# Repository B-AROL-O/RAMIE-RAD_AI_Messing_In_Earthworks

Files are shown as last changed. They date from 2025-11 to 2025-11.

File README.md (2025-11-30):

---
title: RAMIE-RAD AI Messing In Earthworks
emoji: 🐨
colorFrom: gray
colorTo: pink
sdk: gradio
sdk_version: 5.49.1
app_file: app.py
pinned: false
license: cc-by-sa-4.0
short_description: A local Gradio MCP server controlling a robot platform
tags:
  - mcp-in-action-track-creative
---

# RAMIE

- **Radical**
- **AI**
- **Messing**
- **In**
- **Earthworks**

A local Gradio MCP AI powered wheeled robot, capable of listening, speaking and executing commands, in the vision of the B-AROL-O team

*TRIVIA: The B-AROL-O team likes to use names of Italian wines as acronyms for robots. [RAMIE](https://nebbiaeluce.com/producer/ramie-perosa-argentina/) is a local red wine from my village*

*TRIVIA: "Vino" is the Italian word for Wine. Intel OpenVINO AI runtime is the perfect runtime to run a robot named after an italian wine by italian developers*

## Scope

The scope of this repository is to document the Hugging Face MCP 1° birthday hackaton

The scope of this repository is to document all instruction to replicate in full the robot project

Work is divided in two parts:

- Work that is qualifying for the hackaton itself, that was started 2025-11-14, this includes learning GRADIO, learning MPC, preparing the MCP tools, interfacing ollama with AI models needed

- Work that is not qualifying for the hackaton and was recycled from previous projects and is in this repository in order to make a complete set of instructions to replicate this project. This include the electronics, the mechanical part of the robot, learning the compute board, and learning that was done for ollama testing of the microphone

This felt like a good chance to gather all the disparate documentation and work done over the years in one tidy set of insttructions that can be followed to make one complete platform end to end with the GRADIO/MCP/OLLAMA software being the keystone that glue it all together.

# Documentation

Designs marked with '*(not qualifying for hackaton)* ' are older recycled design that are here for documentation, instruction and completeness purposes and are not qualifying for the scope of the hackaton.  They are either taken as is, or lightly/heavily adapted to serve for the scope of the Hackaton.

## Mechanical Design

I design in OpenSCAD as I like making geometries as code and I like doing everything parametric.

I decided that the robots should be powered by 18650 batteries. Target configuration is 2S2P. For RAMIE I went with an inverted design that is soldered 4S1P to get 14.8V nominal voltage to be compatible with the input regulator for the Latte Panda Lite Board.

- [MEC: 18650 Battery Holder](/Mechanical/Battery%20Holder%2018650%20OpenSCAD) *(not qualifying for hackaton)*
- [MEC: Wheeled Platform](/Mechanical/Wheeled%20Platform%20OpenSCAD) *(not qualifying for hackaton)*

The robot platform is the one I am designing for Latte Panda Lite Board powered AI robots, it was a good fit for this hackaton

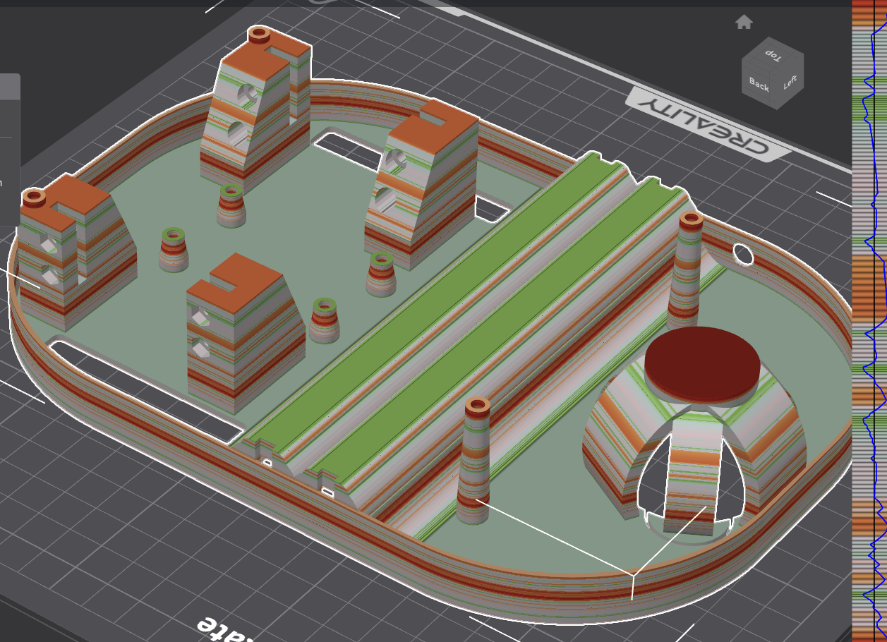
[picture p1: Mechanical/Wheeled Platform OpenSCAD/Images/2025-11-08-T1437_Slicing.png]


## Board Motor Screen

Interfaces with a UART bidirectional link with the SBC, answer to a serial protocol, controls two servos and a LCD screen. Choosen because I had a bounch assembled in a drawer and working firmware to start from.

- [ELN: Board Motor Screen](/Electronics/Board%20motor%20screen) *(not qualifying for hackaton)*
- [FW: Board Motor Screen](/Firmware/Motor%20Board%20Atmel%20AT324PA) *(not qualifying for hackaton)*
- [FW: Test Bench Serial Communication](/Firmware/Test%20Bench%20Parser) *(not qualifying for hackaton)*
- [FW: Test Bench Motion Orchestrator](/Firmware/Test%20bench%20motion%20orchestration)
- [SW: Python demos to test communication between Host computer and board](/Software/Demo_Host_Serial_Communication/)
- [SW: Python demos to test communication between SBC and board](/Software/Demo_SBC_Serial_Communication/)

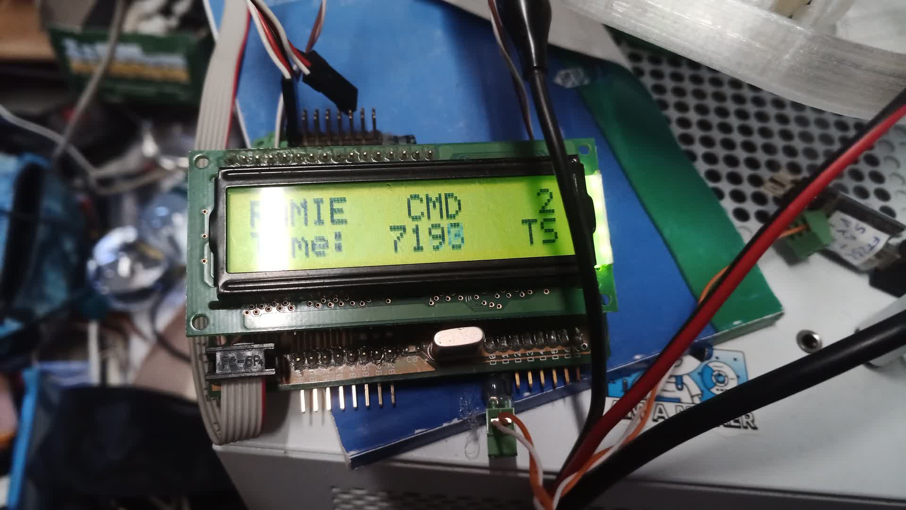
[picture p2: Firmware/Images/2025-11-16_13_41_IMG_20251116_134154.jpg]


# SBC Latte Panda Mu N100 16GB

I lost count of the SBCs I tested for my ultimate goal of making a general robot that expresses a degree of general intelligence with local compute only. The N100 16GB could be it, it has the memory, bandwidth, compute and power envelope to run useful LLMs on the go.

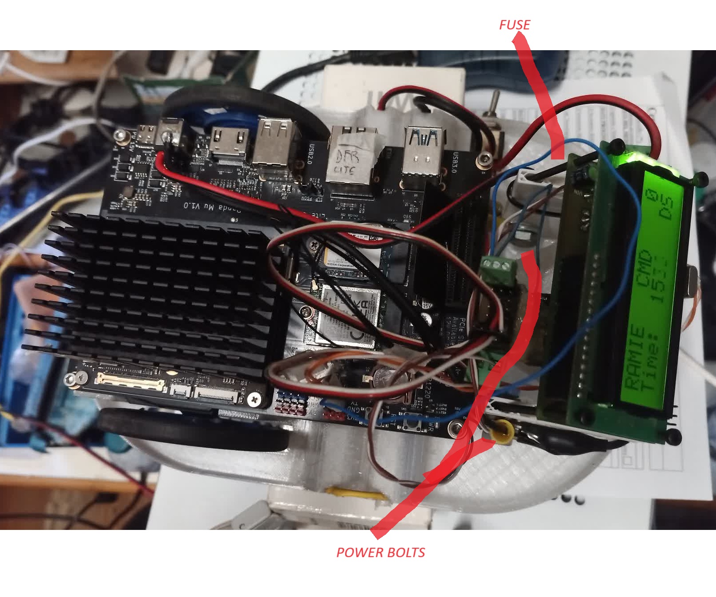
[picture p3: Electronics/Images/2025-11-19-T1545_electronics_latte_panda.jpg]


## Luckfox PicoKVM

I always have trouble accessing SBC headless, I finally got a 49€ KVM to mitigate the issue and free myself from using discrete keyboard and mouse

[Luckfox PicoKVM Instructions](/Software/Luckfox%20PicoKVM)

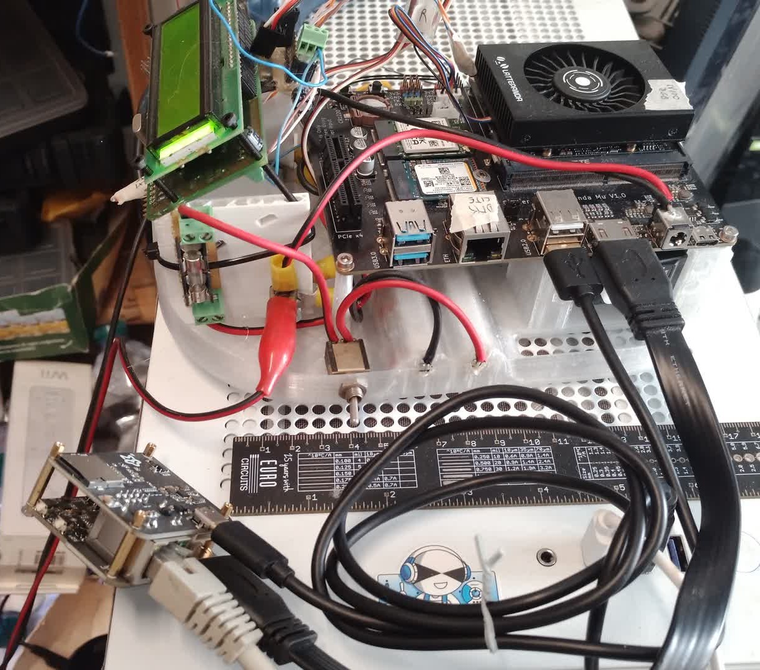
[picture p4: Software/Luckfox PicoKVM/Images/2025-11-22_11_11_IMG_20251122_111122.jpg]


## INSTALL UBUNTU

Install Ubuntu 24.04 Server LTS on the SBC and configure network and storage

[Ubuntu 24.04 Server Install Instructions](/Software/Ubuntu%2024_04%20server%20LTS)

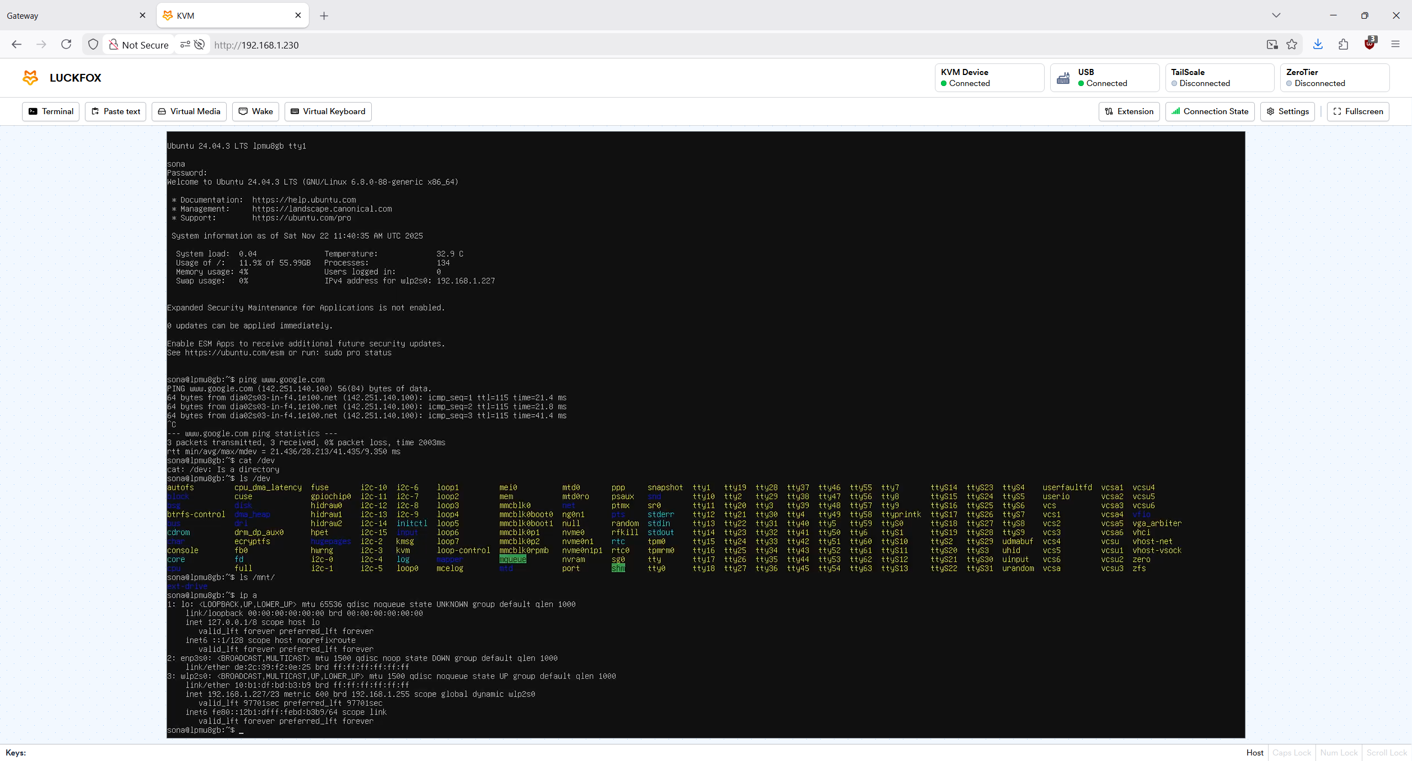
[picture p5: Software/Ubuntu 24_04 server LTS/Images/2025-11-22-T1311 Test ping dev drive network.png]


## Luckfox PicoKVM

I always have trouble accessing SBC headless, I finally got a 49€ KVM to mitigate the issue and free myself from using discrete keyboard and mouse

[Luckfox PicoKVM Instructions](/Software/Luckfox%20PicoKVM)



## TTYS0 SSH PUTTY SERIAL

Configure the GRUB to use ttyS0 as UART serial interface to let the host connect via putty via USB to UART FTDI adapter

[TTYS0 SERIAL GRUB CONFIGURATION](/Software/ttys0%20SSH)

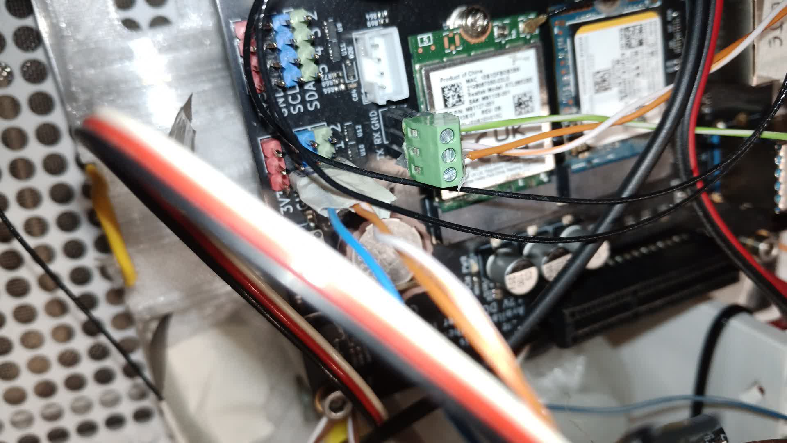
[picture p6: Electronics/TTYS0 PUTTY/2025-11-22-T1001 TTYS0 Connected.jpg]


## VS Code Remote

Use VS code on host machine with remote SSH plugin to evelop and run code directly on the SBC via WiFi radio

[VS Code Remote Instructions](/Software/VS%20Code%20Remote%20Development%20on%20SBC)

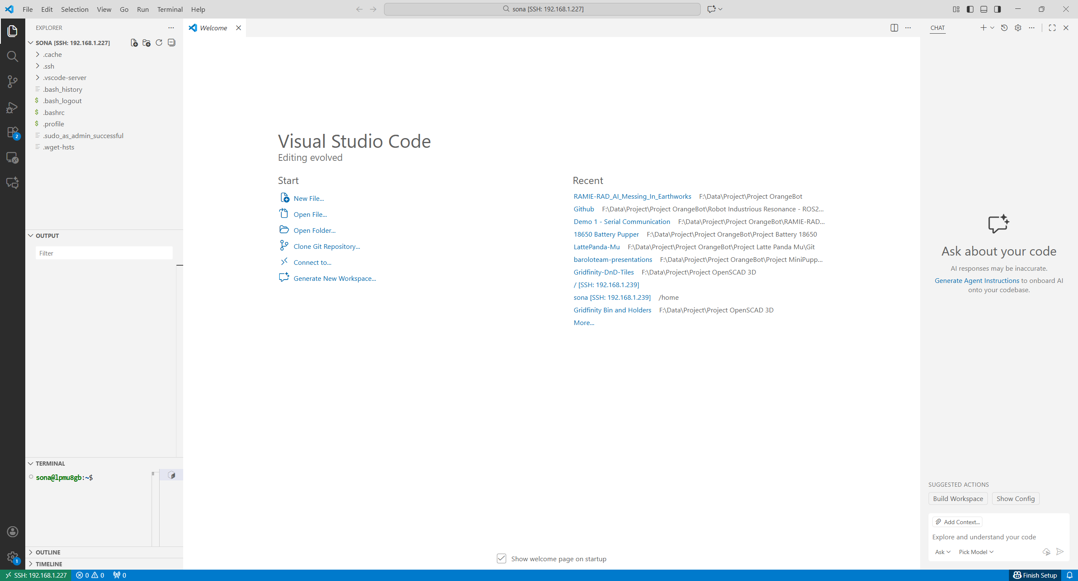
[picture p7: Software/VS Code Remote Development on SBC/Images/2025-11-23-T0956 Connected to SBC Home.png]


# Battery Teleoperation SSH WiFI

Final test with the robot under battery power with SBC, AT324, WiFI and motors running with SSH teleoperation form keyboard

https://github.com/user-attachments/assets/86d634cf-5507-45de-8ebf-013d29c1c32a

# Ollama GRADIO LLamaindex

The robot hosts and run locally GRADIO

There are two chats

One is the chat to ask about RAMIE capability using LLamaindex to rag the specifications

The second has a tool that attaches with a MCP tool to the motors and genereate serial command for the robot to execute

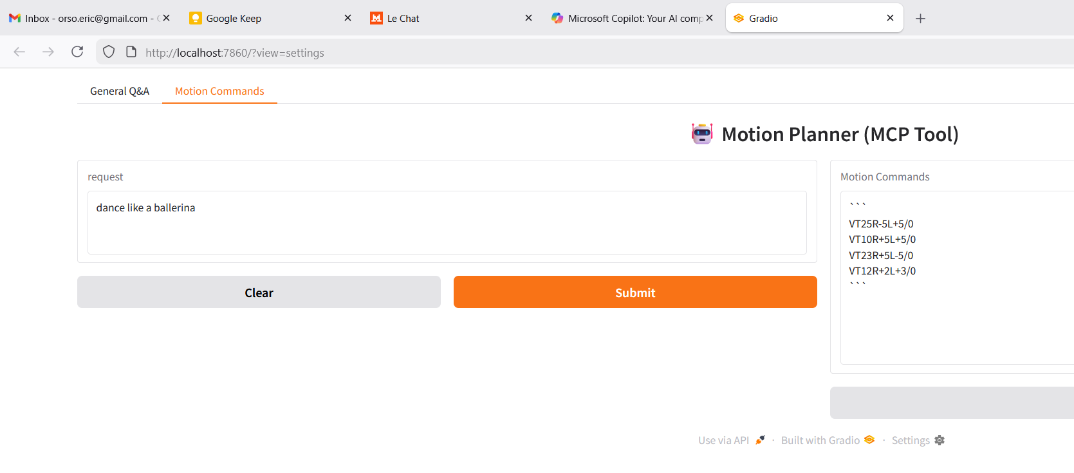
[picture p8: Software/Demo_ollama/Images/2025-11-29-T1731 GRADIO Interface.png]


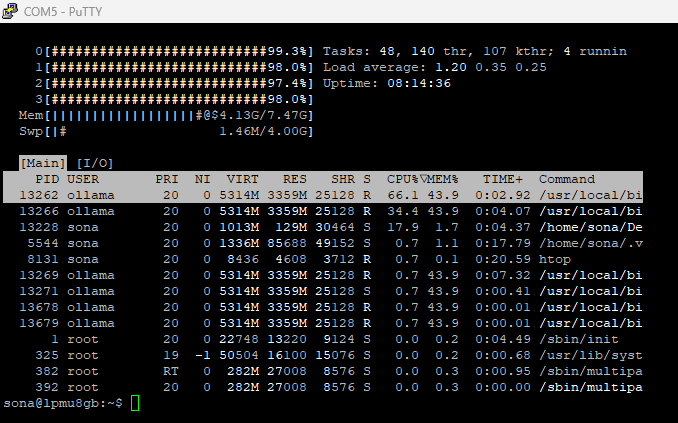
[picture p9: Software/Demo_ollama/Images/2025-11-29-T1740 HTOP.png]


# Contributors

- [Orso Eric](https://github.com/OrsoEric)

## Useful Links

- [Huggingface Hackaton](https://huggingface.co/MCP-1st-Birthday) 
- [Huggingface Example Track 2 Creative](https://huggingface.co/spaces/ysharma/sample5-hackathon-space-submission/blob/main/README.md)
- [Huggingface space](https://huggingface.co/spaces/MCP-1st-Birthday/RAMIE-RAD_AI_Messing_In_Earthworks)
- [Huggingface Organization](https://huggingface.co/RAMIE-RAD-AI-Messing-In-Earthworks)
- [Github repository](https://github.com/B-AROL-O/RAMIE-RAD_AI_Messing_In_Earthworks)
- [Github project board](https://github.com/orgs/B-AROL-O/projects/5)

## TRACK

Track 2: MCP in Action

mcp-in-action-track-creative

# Copyright and License

Copyright (C) 2025, B-AROL-O Team, all rights reserved.

NOTE: This repository is based upon https://github.com/arol-polito/python-project-template.
Source code license

The source code contained in this repository and the executable distributions are licensed under the terms of the MIT license as detailed in the LICENSE file.
Documentation license

CC BY-SA 4.0

Please note that your contribution to the project Documentation is licensed under a Creative Commons Attribution-Share Alike 4.0 License. see https://creativecommons.org/licenses/by-sa/4.0/

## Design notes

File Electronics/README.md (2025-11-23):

# Latte Panda Mu Lite Board

I have three modules

N100 8GB Active Cooling

N100 16GB Passive Cooling

N305 16GB (BRICKED Sent back to DF Robot)

---

# Power

| Voltage  | Current | Power | Note |
|---|---|---|-|
| 18V |  | STOP |
| +10 | +10 | FORWARD 100mm/s |
| -10 | -10 | BACKWARD 100mm/s |
| -10 | +10 | COUNTERCLOCKWISE 180°/s |
| +10 | -10 | CLOCKWISE 180°/s |

# Battery Teleoperation SSH WiFI

Final test with the robot under battery power with SBC, AT324, WiFI and motors running with SSH teleoperation form keyboard

https://github.com/user-attachments/assets/86d634cf-5507-45de-8ebf-013d29c1c32a

## SETUP UART ACCESS TO TTYS0 DEBUG UART

Modify GRUB so that the operating system connects tothe serial port for access

```
cat /etc/default/grub
sudo nano /etc/default/grub
```

Edit the GRUB to make sure the following lines woirk

```
 GNU nano 7.2                                                                                                          
/etc/default/grub *
# If you change this file, run 'update-grub' afterwards to update
# /boot/grub/grub.cfg.
# For full documentation of the options in this file, see:
#   info -f grub -n 'Simple configuration'

GRUB_DEFAULT=0
GRUB_TIMEOUT_STYLE=hidden
GRUB_TIMEOUT=0
GRUB_DISTRIBUTOR=`( . /etc/os-release; echo ${NAME:-Ubuntu} ) 2>/dev/null || echo Ubuntu`

 #2025-11-22 Adding the serial port access via ttyS0 that I ound is the debug consol
GRUB_CMDLINE_LINUX_DEFAULT="console=ttyS0,115200n8"
GRUB_TERMINAL="console serial"
GRUB_SERIAL_COMMAND="serial --speed=115200 --unit=0 --word=8 --parity=no --stop=1"

# If your computer has multiple operating systems installed, then you
# probably want to run os-prober. However, if your computer is a host
# for guest OSes installed via LVM or raw disk devices, running
# os-prober can cause damage to those guest OSes as it mounts
# filesystems to look for things.
#GRUB_DISABLE_OS_PROBER=false

# Uncomment to enable BadRAM filtering, modify to suit your needs
# This works with Linux (no patch required) and with any kernel that obtains
# the memory map information from GRUB (GNU Mach, kernel of FreeBSD ...)
#GRUB_BADRAM="0x01234567,0xfefefefe,0x89abcdef,0xefefefef"

# Uncomment to disable graphical terminal
#GRUB_TERMINAL=console

# The resolution used on graphical terminal
# note that you can use only modes which your graphic card supports via VBE
# you can see them in real GRUB with the command `vbeinfo'
#GRUB_GFXMODE=640x480

# Uncomment if you don't want GRUB to pass "root=UUID=xxx" parameter to Linux
#GRUB_DISABLE_LINUX_UUID=true

# Uncomment to disable generation of recovery mode menu entries
#GRUB_DISABLE_RECOVERY="true"

# Uncomment to get a beep at grub start
#GRUB_INIT_TUNE="480 440 1"
```

Update grub, whatever that means

```
sudo update-grub
```

Log

```
sona@sona-lp-n100-8gb:~$ sudo update-grub
Sourcing file `/etc/default/grub'
Generating grub configuration file ...
Found linux image: /boot/vmlinuz-6.14.0-32-generic
Found initrd image: /boot/initrd.img-6.14.0-32-generic
Found linux image: /boot/vmlinuz-6.14.0-29-generic
Found initrd image: /boot/initrd.img-6.14.0-29-generic
Found memtest86+ 64bit EFI image: /boot/memtest86+x64.efi
Warning: os-prober will not be executed to detect other bootable partitions.
Systems on them will not be added to the GRUB boot configuration.
Check GRUB_DISABLE_OS_PROBER documentation entry.
Adding boot menu entry for UEFI Firmware Settings ...
done
```

Reboot and see if you bricked the OS

```
sudo reboot
```

So, it works and doesn't. On the screen I see ```unsupported port speed``` and on the serial terminal on the host I see that at 9600 I can see the dump

I redid the instruction setting the speed to 115200

---

#### 2025-11-22-T0900 Test Board 2

I powered bypassing the jack and the power button does not work

I connected jack, disconnected uC serial, and it takes a while to power on

I see nothing on the debug uart ttys0

Screen shows no sign of activity

A single click on the power button will shut down the SBC

Shutdown doesn't work

#### 2025-11-22-T1041 Test Board 1

Powered

Checksum error a few reboots

Powered on turn on screen

tested debug uart, see nothing

---

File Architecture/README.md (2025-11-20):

# ARCHITECTURE

## RAMIE

RAMIE is an acronym for:
- RAD Radical
- AI
- Messing
- In
- Earthworks

RAMIE is an MVP AI robot meant to use local 4B LLMs as poor's man AGI and achieve general robotics to an extent.

RAMIE showcasses an end to end STT LLM TTS workflow using MCP tools to sense the robot state and control the robot actions.

RAMIE is menat to run 100% locally without internet connection, all within a small mobile robots, cost, power, memory and compute envelopes.

It has proven most challenging finding an SBC capable of such feats.

## SPECIFICATIONS

- Power: 40 W
- Batttery Duration: ? h
- DoF: 2
- Complexity: MVP

# HARDWARE ARCHITECTURE

## SBC

The single board computer takes care of high level user application and running AI models and required python glue.

RAMIE is powered by the ```Latte Panda Mu N100 16GB``` mounted on a ```Latte Panda Mu Lite Carrier Board```

This board was choosen because of a combination of RAM, RAM bandwidth, compute, power envelope and Intel being one of the two companies in the world that knows how to write drivers and ML frameworks.

## Microcontroller

RAMIE is equipped with a microcontroller board takes care of real time applications, like motor control.

- ```Atmel 324 PA``` 32KB Flash, 4KB SRAM
- ```LCD 2x16``` Display board status
- ```UART 250Kb/s``` Link with the SBC

## Motors

RAMIE moves using two continuous rotation servos using PPM protocol and two wheels with pivot.

Motors are labeled left and right, in this order. The table below will show the robot action when a given speed is sent to the microcontroller board.

| Left Speed  | Right Speed | Robot Motion | 
|---|---|---|
| 0 | 0 | STOP |
| +10 | +10 | FORWARD 100mm/s |
| -10 | -10 | BACKWARD 100mm/s |
| -10 | +10 | COUNTERCLOCKWISE 180°/s |
| +10 | -10 | CLOCKWISE 180°/s |

## Communication Protocol SBC <-> 

Hardware link uses full duplex 250Kb/s link on UART ```ttys4```

The protocol is meant to allow the SBC to read the robot state, and emit robot actions, with the microcontroller firmware taking care of real time operation.

### FEATURE: COMMUNICATION TIMEOUT

The firmware is configured to STOP the motors automatically if no communications is received within a given time limit.

This feature is meant to mitigate the scenario where the SBC application has stalled and the robot will keep executing the last given command, preventing a collision and making it convenient to rearm the robot.

Typical timeout configuration is 1000ms

### FEATURE: DIRECT MODE VS. TIMED MODE

I thought a lot about it, and designed to set of velocity commands to be sent to the SBC.

- Direct Mode: The SBC send a velocity for left and right wheel, and the wheel will move at that speed unless commanded otherwise.
- Timed Mode: The SBC send a timed velocity command that specify a duration in servo step (50Hz). The microcontroller has a queue. This allows the SBC to send a number of motion commands and the microcontroller will execute the commands in sequence for the specified time, then when queue is empty, stop the motors.

Direct Mode is convenient for teleoperation, by binding a velocity to a keystroke down, and velocity zero to keystroke up.

Timed Mode is convenient for LLM orchestration, where the LLM can come up in a single query with a number of motion instructions, and the microcontroller will execute them in sequence. THe SBC isn't going to be convenient for real time anyway, let the microcontroller deal with it.

The microcontroller will seamless switch mode based on last received command, switching will flush the queue of timed commands.

### UART Command Reference (SBC <-> MICROCONTROLLER)

*All messages are ASCII strings terminated by the literal sequence `"/0"` (slash zero). The SBC always sends the terminator; the micro‑controller never sends any data except the replies listed below.*

**RAMIE UART Command Reference (SBC ↔ MC‑U)**  

| Command | Syntax | Arguments | Meaning | Reply (if any) |
|---|---|---|---|---|
| **PING** – refresh communication timeout | `P/0` | – | Resets the internal timeout timer. | None |
| **SIGN** – get robot signature | `SIGN/0` | – | Returns a string identifying the robot. | `RAMIE/0` |
| **REV** – firmware revision | `REV/0` | – | Returns date of current firmware (ISO‑8601). | `2025-11-16/0` |
| **STOP** – emergency stop | `STOP/0` | – | Immediately cuts power to both motors, bypassing acceleration limits and flushes the motion queue. | `STOP/0` |
| **SET VELOCITY** – set constant wheel speed (bypass orchestration) | `VR%sL%s/0` | `R`: right‑wheel speed  (–127 … +127)<br>`L`: left‑wheel speed  (–127 … +127) | Motor controller accepts the two signed bytes and drives each wheel at the requested PWM value. The values are clipped to the legal range. | None |
| **SET TIMED VELOCITY** – enqueue a motion segment | `VT%uR%sL%s/0` | `T`: duration (steps) at 50Hz <br>`R`, `L`: wheel speeds as above | The controller stores the tuple *(right, left, duration)* in its internal queue. When no other command is received, it executes each queued segment sequentially and stops automatically after the last step. Duration is an integer multiple of **1 step = 20 ms** (i.e., one 50Hz cycle). | None |
| **GET BATTERY** – read battery voltage | `GETBAT/0` | – | ? | ? |

### Common Notes

- **Terminators** – Every command string must end with the literal characters `/0`. The micro‑controller responds in exactly the same way (if a reply is defined).  
- **Error Handling** – If an unknown or malformed command arrives, the micro‑controller sends back `ERR/0`. No other action is taken.  
- **Speed Units** – The signed byte values represent PPM 
- **Queue Size** – Timed Mode supports up to 16 motion commands before overflowing. Overflow behaviour is flush.
- **Safety** – The servo driver implements a change in command limit from time step to time step, that is speed for position servos, and acceleration for speed servos.

#### Example Session

```
# Reset timeout
P/0

# Query signature
SIGN/0   → RAMIE/0

# Set constant speeds for 2 seconds
VR10L-10/0
VT20R20L20/0      # queue: forward 3 s (since duration=30 steps)
```

The test bench shows the response to orchestration

```
//MOTIONS QUEUED UP
St_wheel_speed_duration mov1{ 10, -10, 5 };   // spin in place for 5 steps
St_wheel_speed_duration mov2{ 20,  20, 3 };    // forward for 3 steps
St_wheel_speed_duration mov3{-15, 15, 4 };     // spin opposite direction
```

```
//SPEED OF THE MOTORS AT EACH ORCHESTRATION STEP
Step:   1 | R:    10 | L:   -10
Step:   2 | R:    10 | L:   -10
Step:   3 | R:    10 | L:   -10
Step:   4 | R:    10 | L:   -10
Step:   5 | R:    10 | L:   -10
Step:   6 | R:    20 | L:    20
Step:   7 | R:    20 | L:    20
Step:   8 | R:    20 | L:    20
Step:   9 | R:   -15 | L:    15
Step:  10 | R:   -15 | L:    15
Step:  11 | R:   -15 | L:    15
Step:  12 | R:   -15 | L:    15
```

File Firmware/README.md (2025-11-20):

# Firmware

I started from Unit Zero 2019 firmware and the uniparser I built over years. Fixed lots of issues glued together and I have the firmware

I spent many years improving on the uniparser library that allows to register a string and a callback with % argument decoding and it works great! Building custom parsers every time was tedious, and the automatic callback with argument is great at reducing work to do new firmware, it works really well.

TODO

# SBC <-> Board Servomotor LCD Communication

I use a UART 250Kb/s link

The communication is done in clear ASCII characters, easy to do by hand

I use the uniparser library that allows to link commands with % delimiter like a printf to do automatic callback functions with arguments that works really well

Define the callback functions

```cpp
extern void handle_ping(void);

extern void handle_sign(void);

extern void handle_revision(void);

extern void handle_stop(void);

extern void handle_set_velocity(int8_t right_speed, int8_t left_speed);

extern void handle_set_velocity_timed(uint8_t time, int8_t right_speed, int8_t left_speed);
```

Register what command triggers what callback function

```cpp
parser.add_cmd( "P", (void *)&handle_ping );

parser.add_cmd( "F", (void *)&handle_sign );

parser.add_cmd( "REV", (void *)&handle_revision );

parser.add_cmd( "STOP", (void *)&handle_stop );

parser.add_cmd( "VR%sL%s", (void *)&handle_set_velocity );

parser.add_cmd( "T%uVR%sL%s", (void *)&handle_set_velocity_timed );
```

From here the uniparser will take care of everything, and automatically do the function call once the command is received

## TIMEOUT

The firmware is configured to kill the motors if no communications is received, assuming that something went wrong.

TODO: Is it implemented? check.

## PING

This command simply refreshes the communication timeout. 

SBC REQUEST: ```P/0```

BOARD ANSWER: none

## SIGN

This command Ask the board to send the signature, it can be the name of the robot

SBC REQUEST: ```SIGN/0```

BOARD ANSWER: ```RAMIE/0```

## REV

This command ask the board for the firmware revision. It's a date in yyyy-mm-dd ISO format

SBC REQUEST: ```REV/0```

BOARD ANSWER: ```2025-11-16/0```

## STOP

This command is the emergency stop. It stops the motors bypassing the speed and acceleration limits.

SBC REQUEST: ```STOP/0```

BOARD ANSWER: ```STOP/0```

TODO: implements the limit removal

##  SET VELOCITY

Set target velocity of left and right wheels. It is limited by the acceleration of the driver, a safety and continuity measure.

Using this command sets a constant velocity, and bypasses the motion orchestration. Set speed to zero or ask for STOP to stop.

It has S8 arguments, range -127 to +127.

SBC REQUEST: ```VR%sL%s/0```

BOARD ANSWER: none

##  SET TIMED VELOCITY

This specify a time and two velocities. This will engage the motion orchestration, allowing the SBC to queue up motions in a queue, so that when a new speed is sent, it's queued up for execution.

Robot will automatically stop once the last command in the queue is executed.

It's done it this way so that the SBC driver doesn't have to care for the real time orchestration of motion sequences.

SBC REQUEST: ```VT%uR%sL%s```

BOARD ANSWER: none

The test bench shows the response to orchestration

```
//MOTIONS QUEUED UP
St_wheel_speed_duration mov1{ 10, -10, 5 };   // spin in place for 5 steps
St_wheel_speed_duration mov2{ 20,  20, 3 };    // forward for 3 steps
St_wheel_speed_duration mov3{-15, 15, 4 };     // spin opposite direction
```

```
//SPEED OF THE MOTORS AT EACH ORCHESTRATION STEP
Step:   1 | R:    10 | L:   -10
Step:   2 | R:    10 | L:   -10
Step:   3 | R:    10 | L:   -10
Step:   4 | R:    10 | L:   -10
Step:   5 | R:    10 | L:   -10
Step:   6 | R:    20 | L:    20
Step:   7 | R:    20 | L:    20
Step:   8 | R:    20 | L:    20
Step:   9 | R:   -15 | L:    15
Step:  10 | R:   -15 | L:    15
Step:  11 | R:   -15 | L:    15
Step:  12 | R:   -15 | L:    15
```

I need to decide how big is an orchestration step. It should be a finite multiple of 50Hz. I'm thinking 1 mean 100ms. So the maximum 255 means 25.5s

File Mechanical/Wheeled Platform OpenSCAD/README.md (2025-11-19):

# Wheeled Platform

This was lots of work

## SPECIFICATIONS

- Latte Panda Lite Board
- 2S2P battery holder
- Ping Pong pivot ball
- HS422 wheeled servo motors
- AT324 LCD motor controller

## Pivot Ball

I did a fancy geometry to hold a 40mm ping pong ball as pivot. The three petals cut into the base and serve as springs to pull out the ball and hold it gently letting it rotate. All with the heights nailed down to get it leveled.

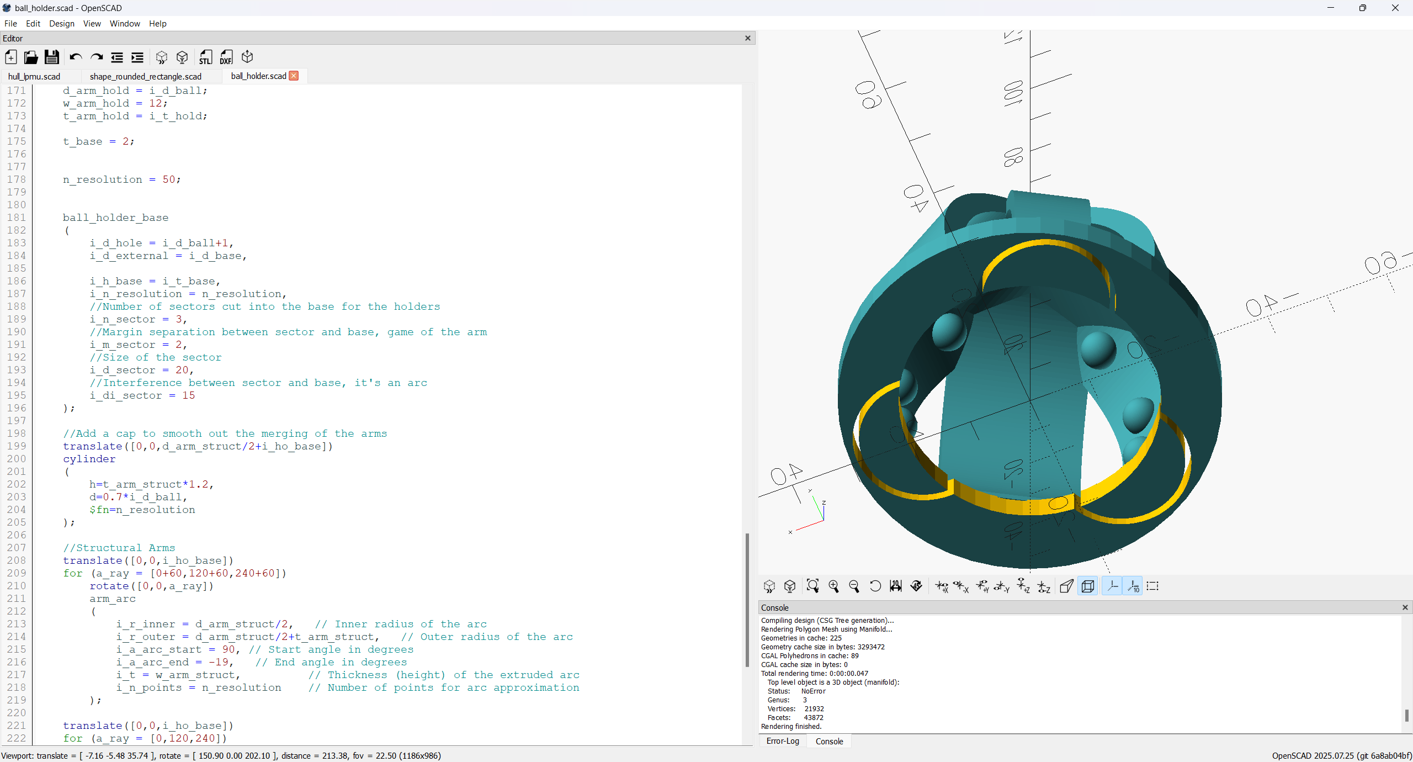
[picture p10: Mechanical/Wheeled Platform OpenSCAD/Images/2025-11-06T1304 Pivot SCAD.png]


## 2S2P Inverted Quad 18650 Holder

Another fancy geometry to hold four batteries with parametric size inverted with the tollerances nailed down so it stays when inverted but can be pulled out. Needs support to print inverted.

I considered various layouts

For a Raspberry Pi dual battery design I can shrink it enormously, that's what I started with, but then pivoted to Latte Panda Mu Board

This version has two banks of two batteries, but ultimately is a lot wider.

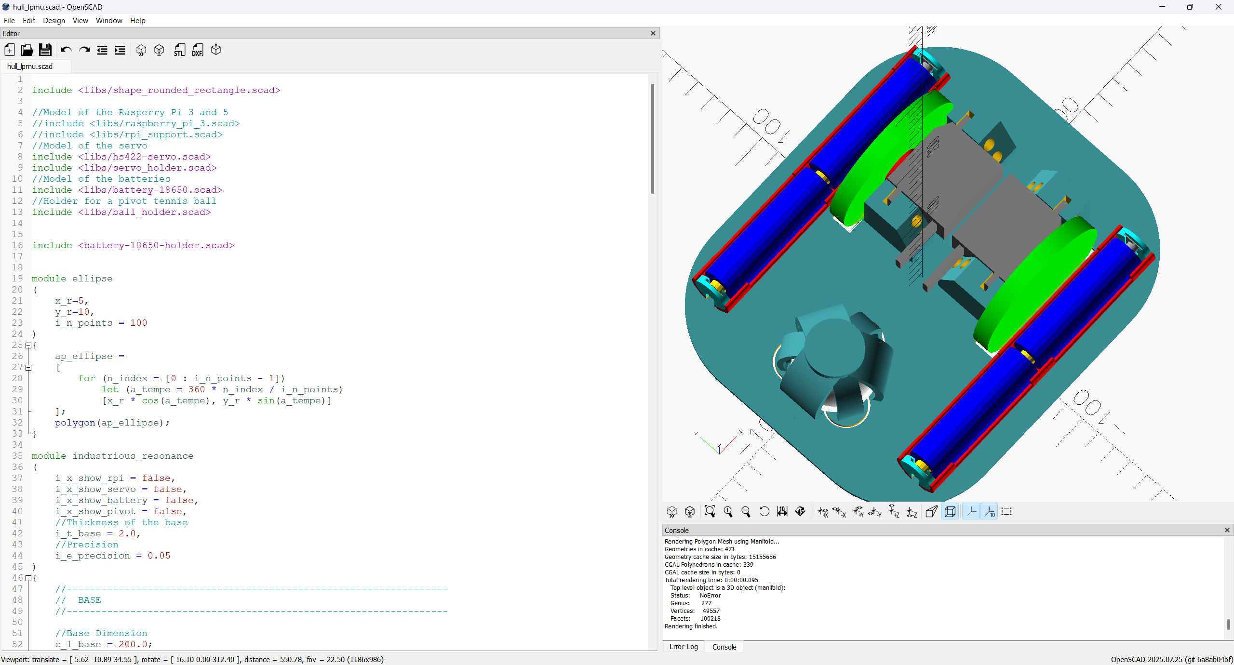
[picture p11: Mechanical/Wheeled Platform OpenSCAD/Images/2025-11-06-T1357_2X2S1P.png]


Ultimately I decided to do it along the width in between wheels and pivot. There is a variation where the batteries stays lengthwise but it makes it much bigger

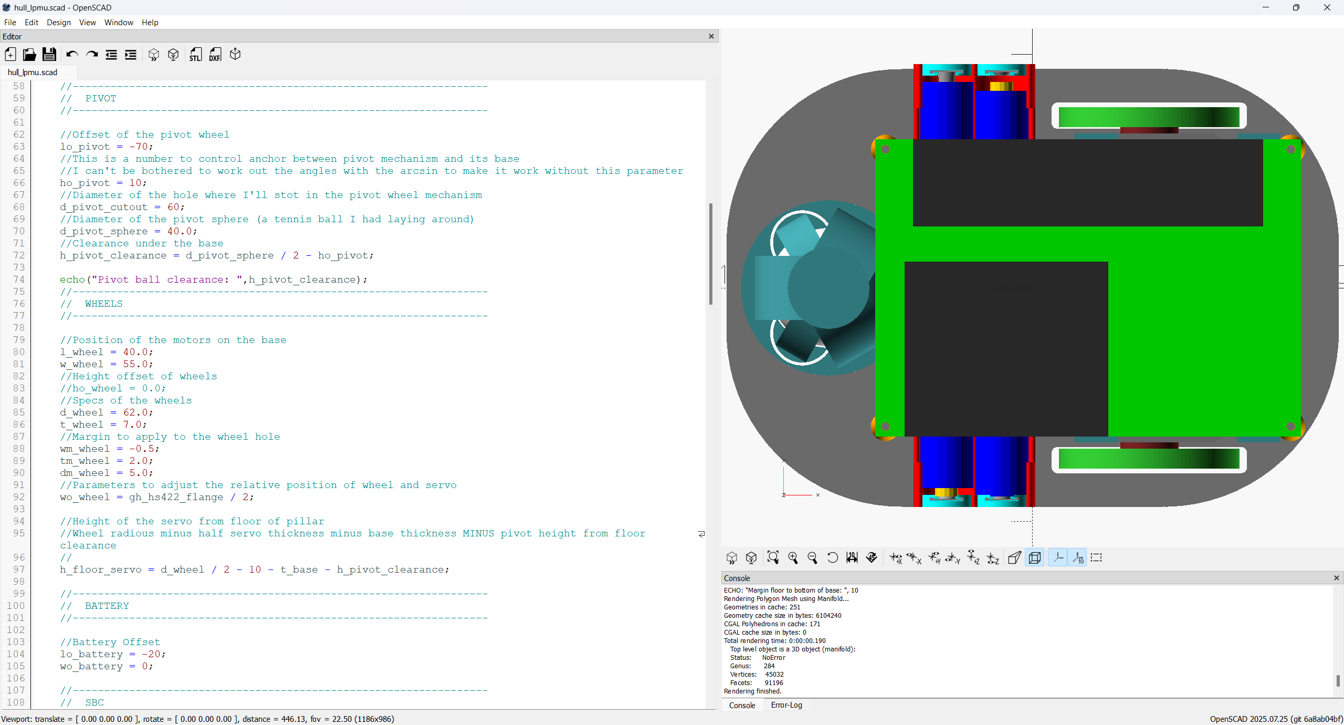
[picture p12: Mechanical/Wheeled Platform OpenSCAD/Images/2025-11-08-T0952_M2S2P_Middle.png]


Then I designed an inverted battery pack to load from below. Much harder to design but worth it.

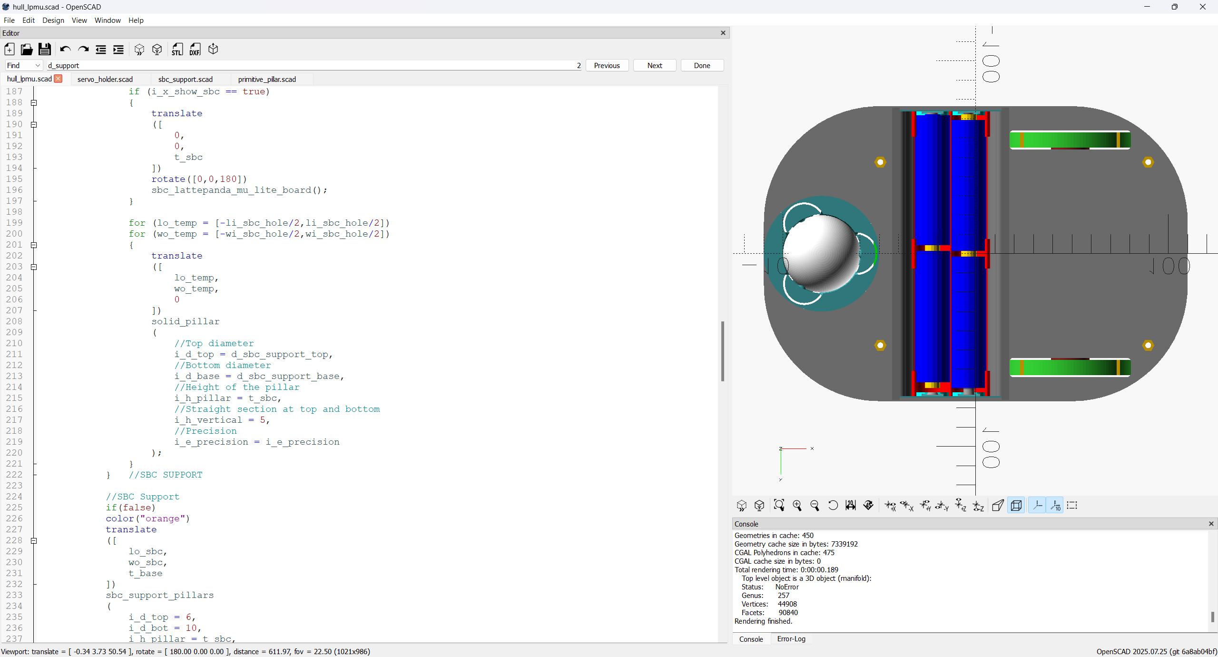
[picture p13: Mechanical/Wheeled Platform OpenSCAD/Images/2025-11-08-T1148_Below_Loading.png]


## HS422 Servo Holder

I have pillars serving as servo holders, I did all the parameters to nail down tollerances and height to keep level, and merged with the SBC pillars.

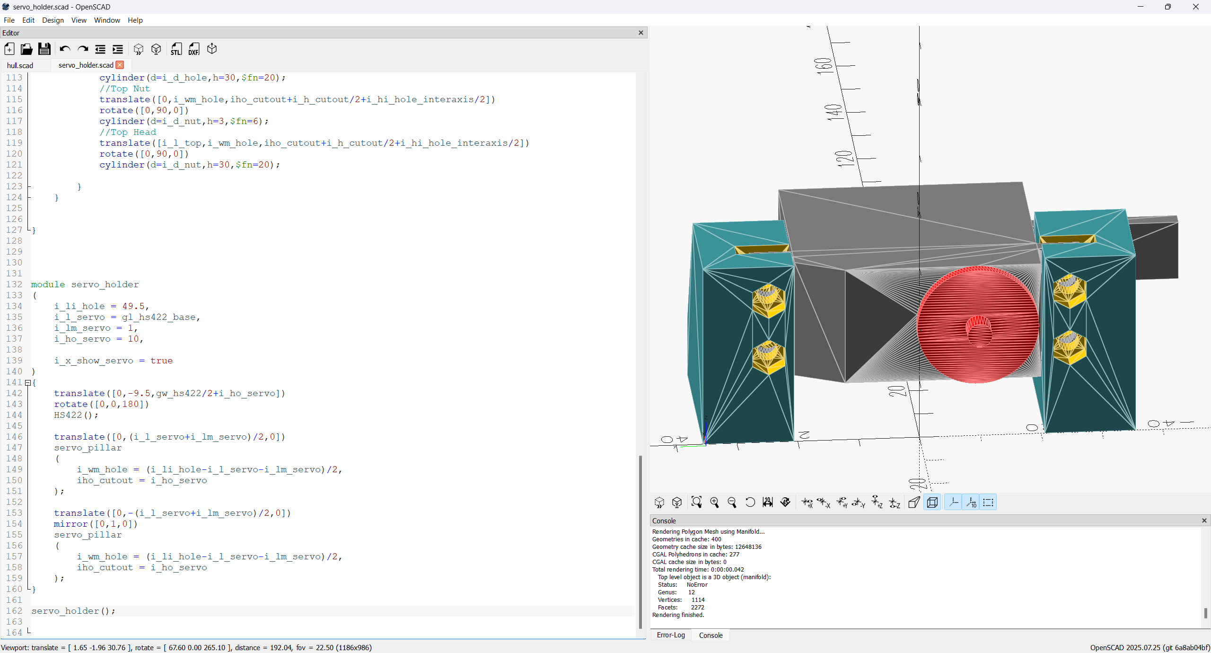
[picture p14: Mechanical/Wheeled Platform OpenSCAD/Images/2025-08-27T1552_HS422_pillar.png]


## AT324 Board

Constructing a sloped wall to support the microcontroller board with LCD

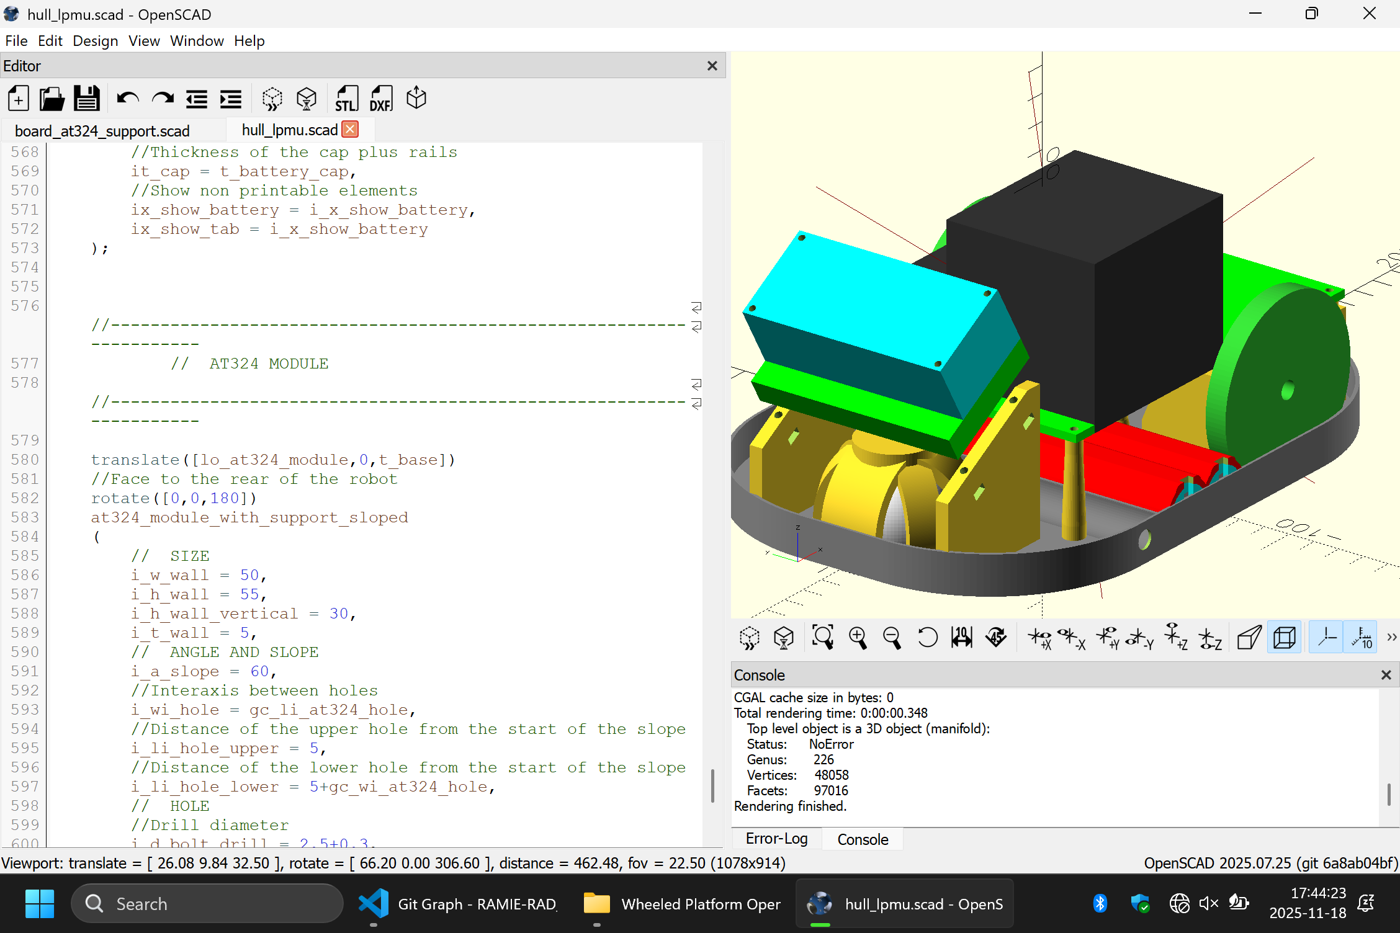
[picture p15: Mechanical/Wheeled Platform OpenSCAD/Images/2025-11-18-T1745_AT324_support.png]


As additional consideration, I can use the support to bolt the power connectors so I have positive and negative side

I whould think of additional structural supports

The rear looks ripe for a camera attachment

Print failed, I did it quick in the evening and failed to use right size and do proper support, it's still useable for the prototype, and I got the bolts right

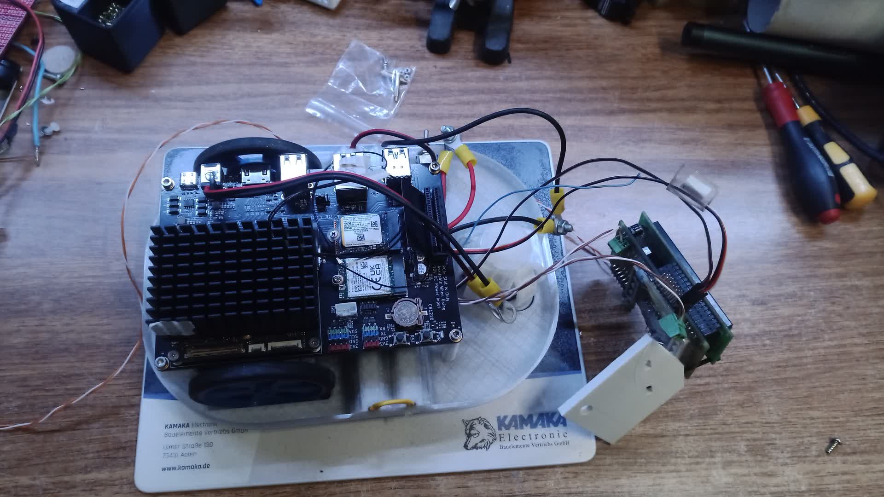
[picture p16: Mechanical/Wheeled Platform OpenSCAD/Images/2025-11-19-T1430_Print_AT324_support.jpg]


Used hotglue to install the support, and it all works well enough.

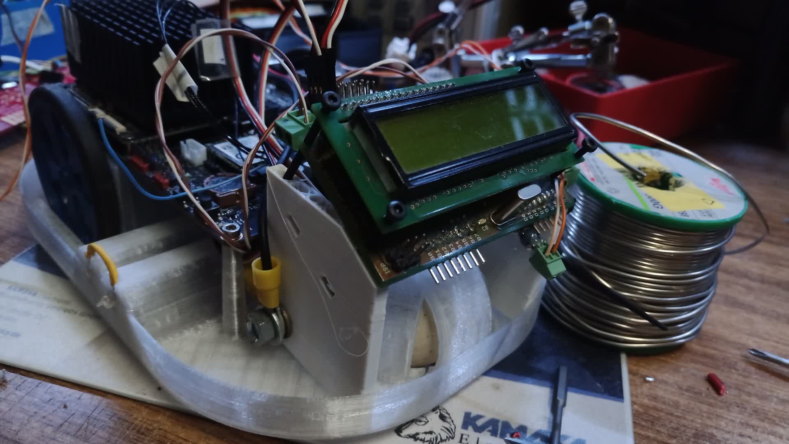
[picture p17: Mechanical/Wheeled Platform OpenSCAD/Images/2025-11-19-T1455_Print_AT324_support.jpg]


## Final Assembly

I did a bath tub style holder with all the components and it turned out okay

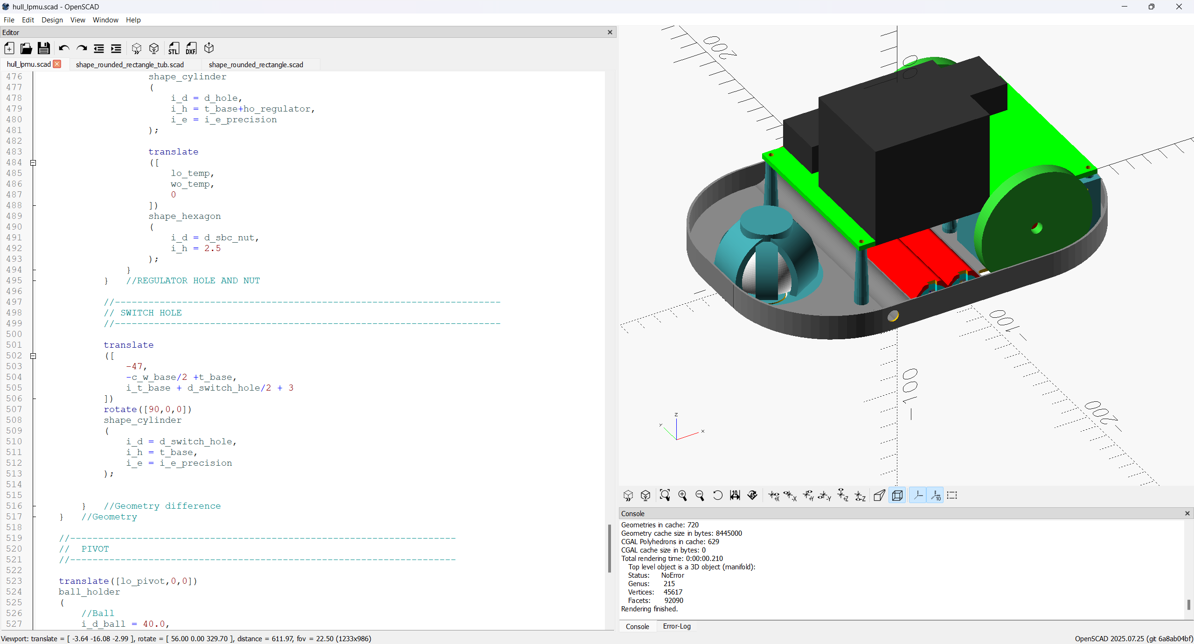
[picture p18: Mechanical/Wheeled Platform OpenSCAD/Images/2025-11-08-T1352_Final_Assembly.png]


Generated the STL and Printed with my Creality K2 with auto loader. I decided to use PETG transparent filament and it came out great! The tollerances are PERFECT.



### TOP VIEW

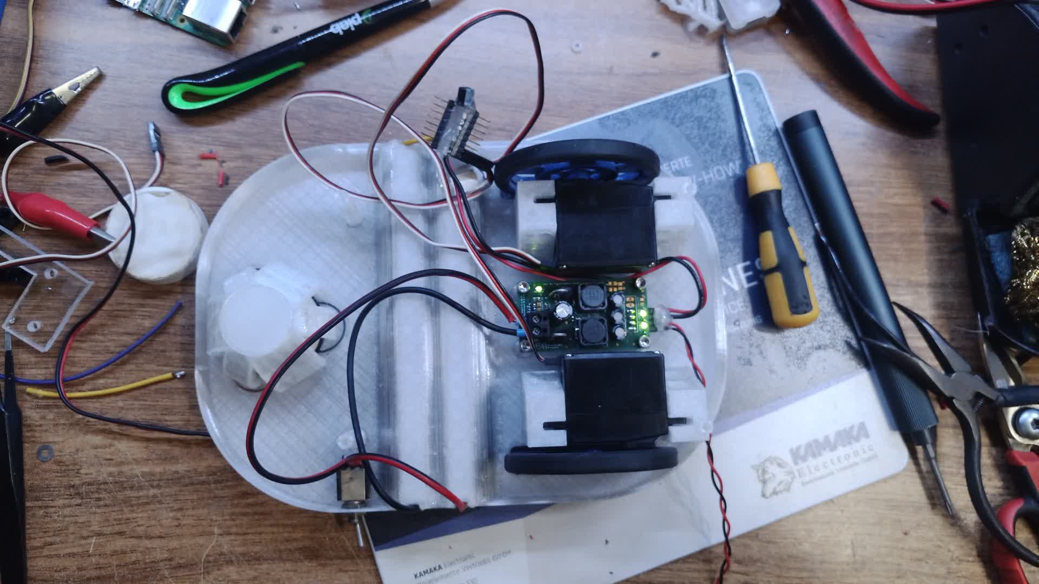
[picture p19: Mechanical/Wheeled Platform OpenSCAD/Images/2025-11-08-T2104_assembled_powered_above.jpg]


### BOTTOM VIEW

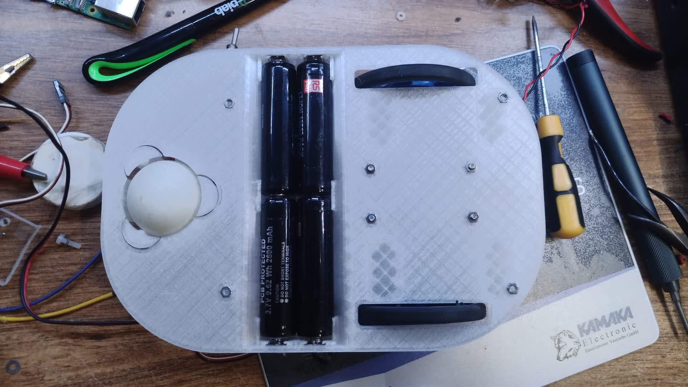
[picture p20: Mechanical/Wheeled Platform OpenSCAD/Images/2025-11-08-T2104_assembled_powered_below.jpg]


### WITH LATTE PANDA

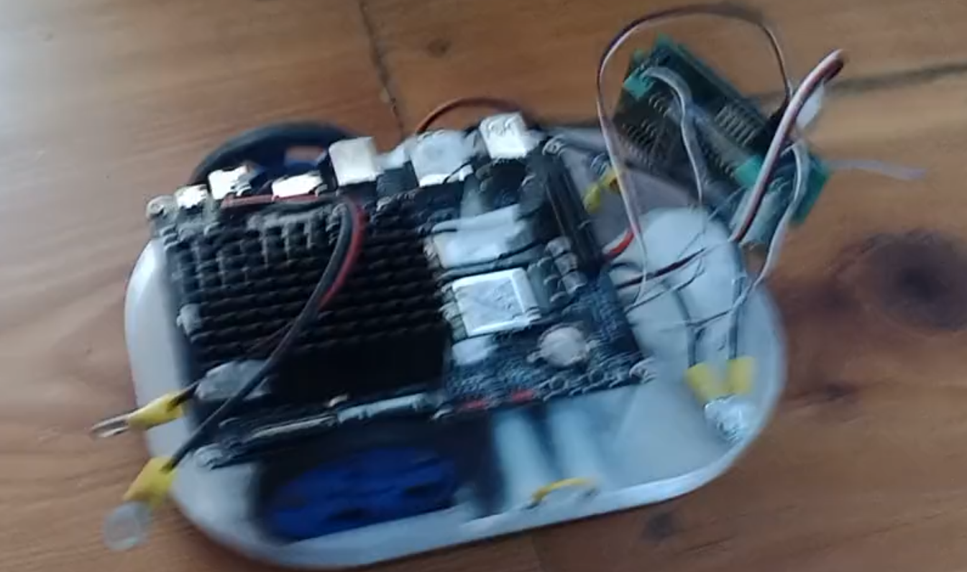
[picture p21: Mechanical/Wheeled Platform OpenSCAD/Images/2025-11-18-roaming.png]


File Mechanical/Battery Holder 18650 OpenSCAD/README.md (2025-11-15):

# 18650 Battery Holder

This is a design for a robot battery holder

# Battery with PCB protection

Length measured to the tip of the button

| Battery | Diameter [mm] | Length [mm] | Capacity [mAh] | Note |
|---|---|---|---|---|
| UltraFlre LI IONBRC  |  18 | 680 | 4800 | I think the capacity is a scam|
| RSPRO LI ION PCB |  18 | 710 | 2600 | |

# Battery Tab 

[RS Component Buy](https://it.rs-online.com/web/p/contatti-per-batterie/3247303)

Size 11x11mm slightly bigger

| Loading | Length [mm] |
|---|---|
| Unloaded | 8 mm |
| Loaded | 3 mm |

# OpenSCAD

Modeling of the parts

## Tab with Spring

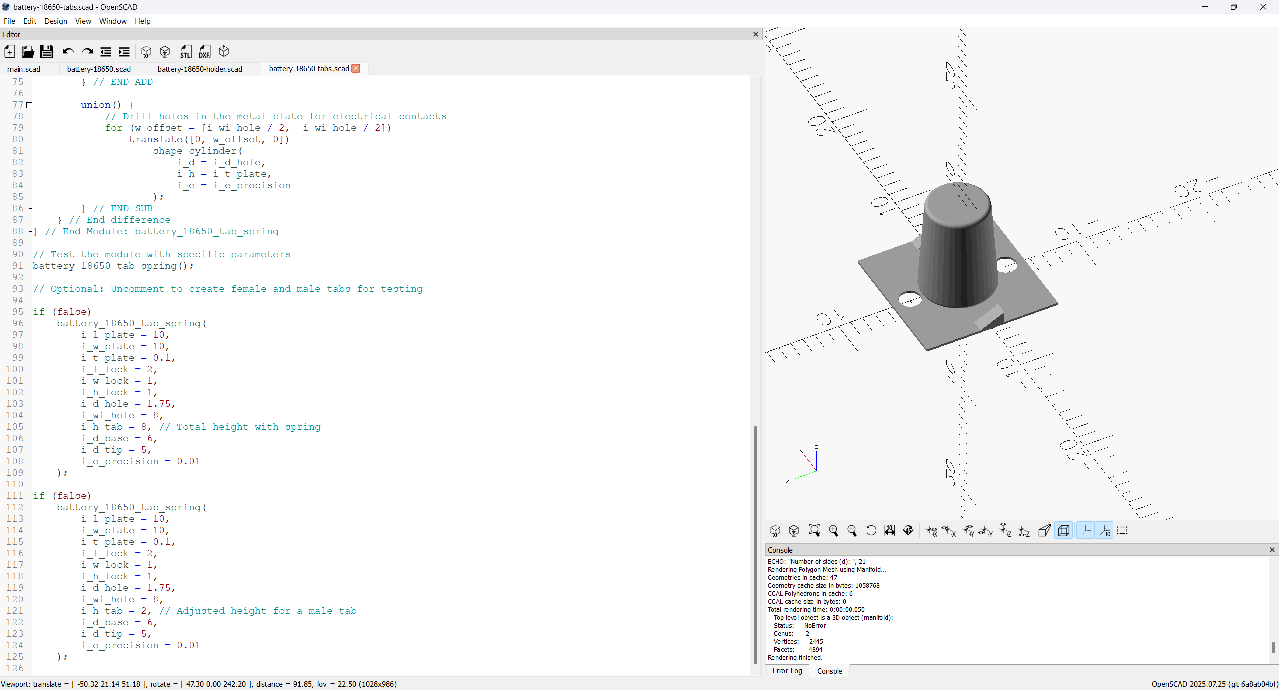
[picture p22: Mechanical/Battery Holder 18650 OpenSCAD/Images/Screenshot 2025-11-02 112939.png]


## Endcap for the battery holder

OpenSCAD

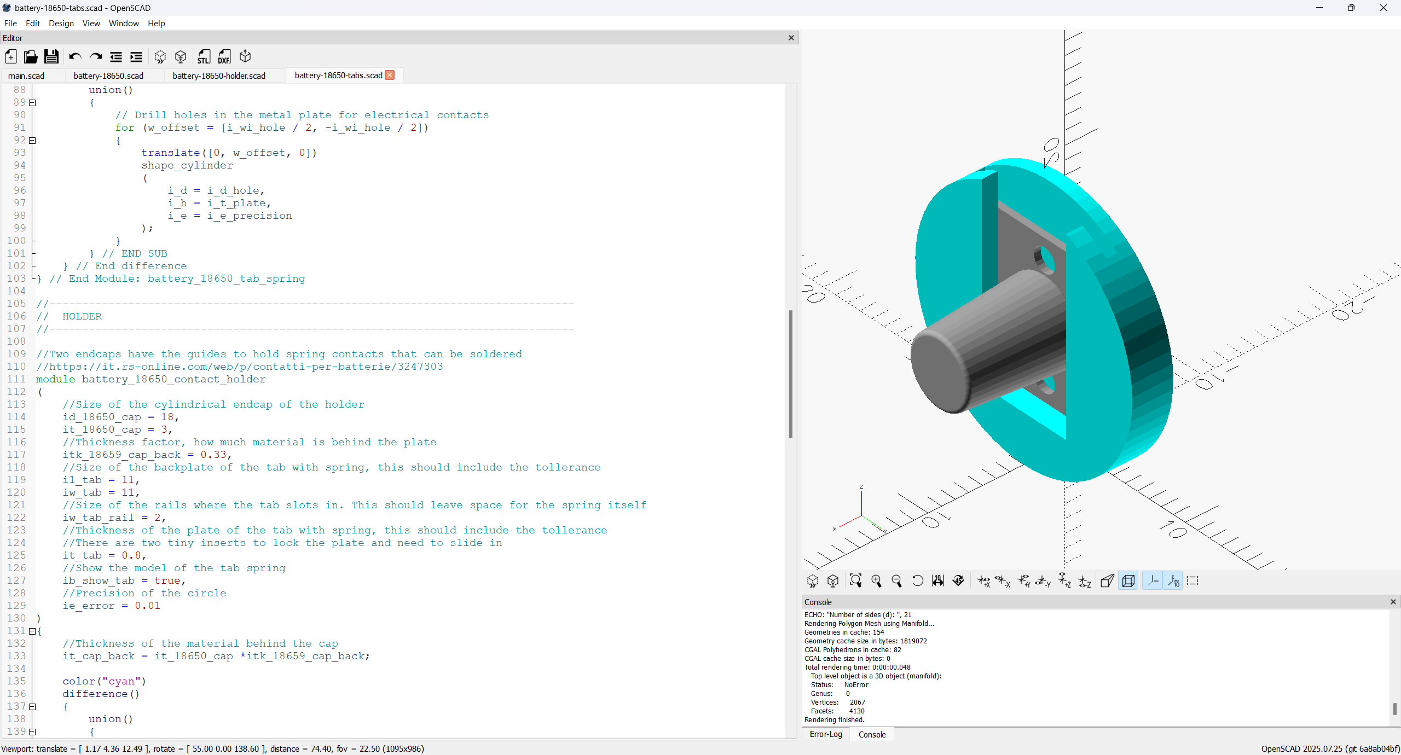
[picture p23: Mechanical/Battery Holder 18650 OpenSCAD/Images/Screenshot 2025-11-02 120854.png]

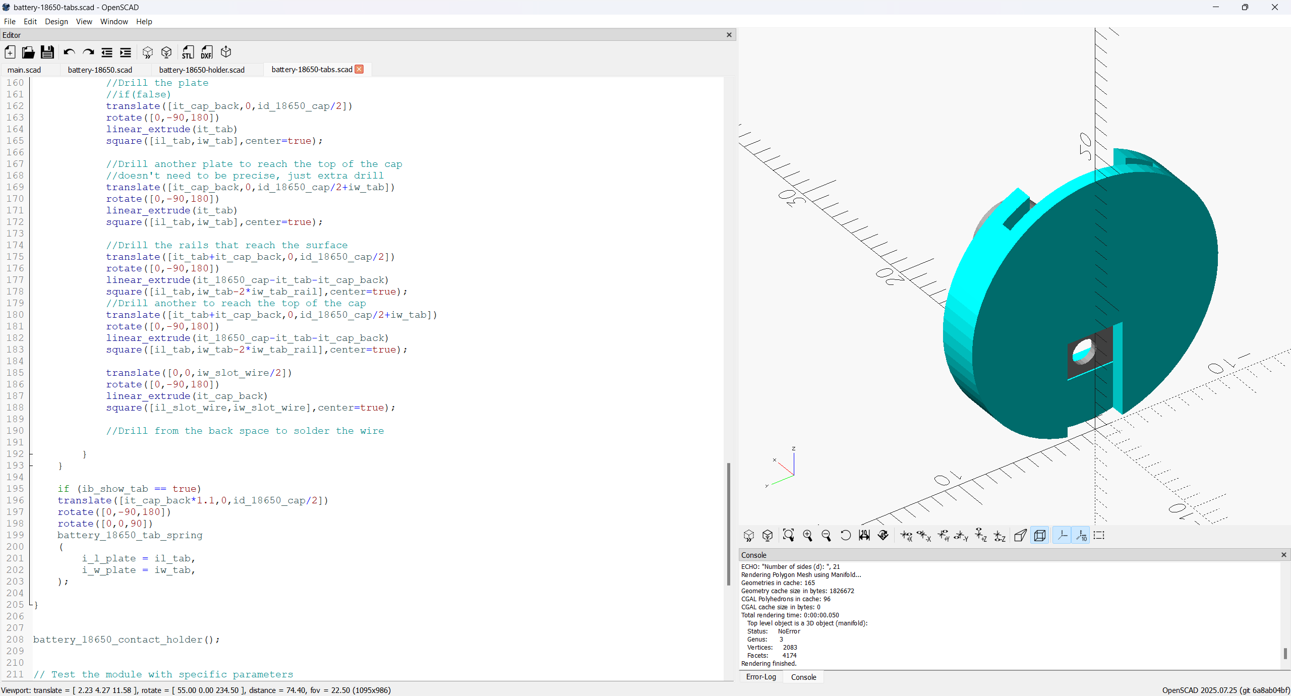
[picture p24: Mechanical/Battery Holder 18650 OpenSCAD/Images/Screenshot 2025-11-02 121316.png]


Printed to test tollerances

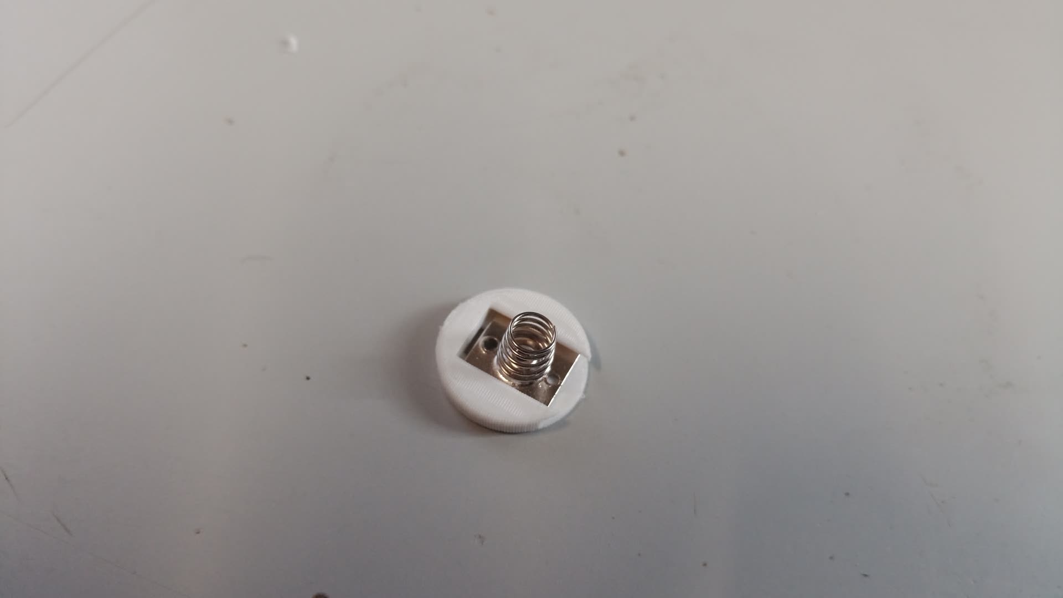
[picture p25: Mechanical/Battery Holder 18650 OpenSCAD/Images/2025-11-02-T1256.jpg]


## Holder 1S1P Single Battery

S mean series, P means parallel

3.7V nominal
4.2V max

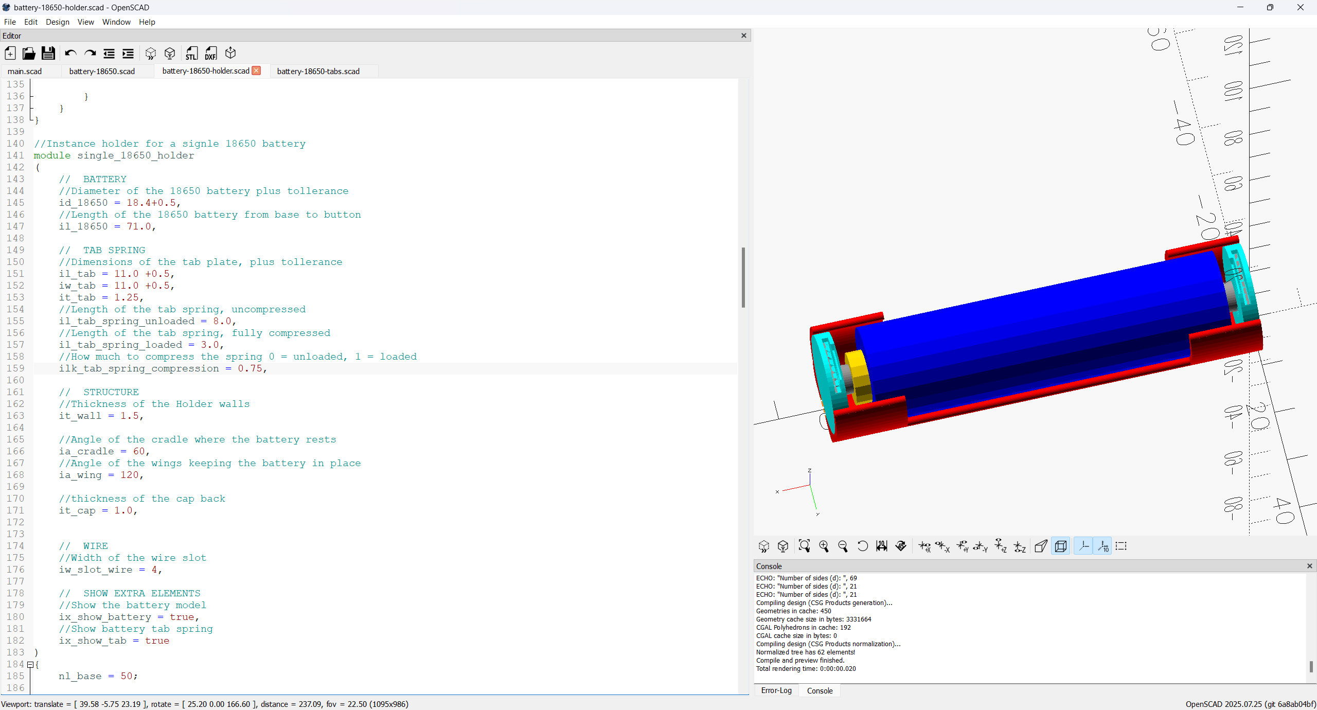
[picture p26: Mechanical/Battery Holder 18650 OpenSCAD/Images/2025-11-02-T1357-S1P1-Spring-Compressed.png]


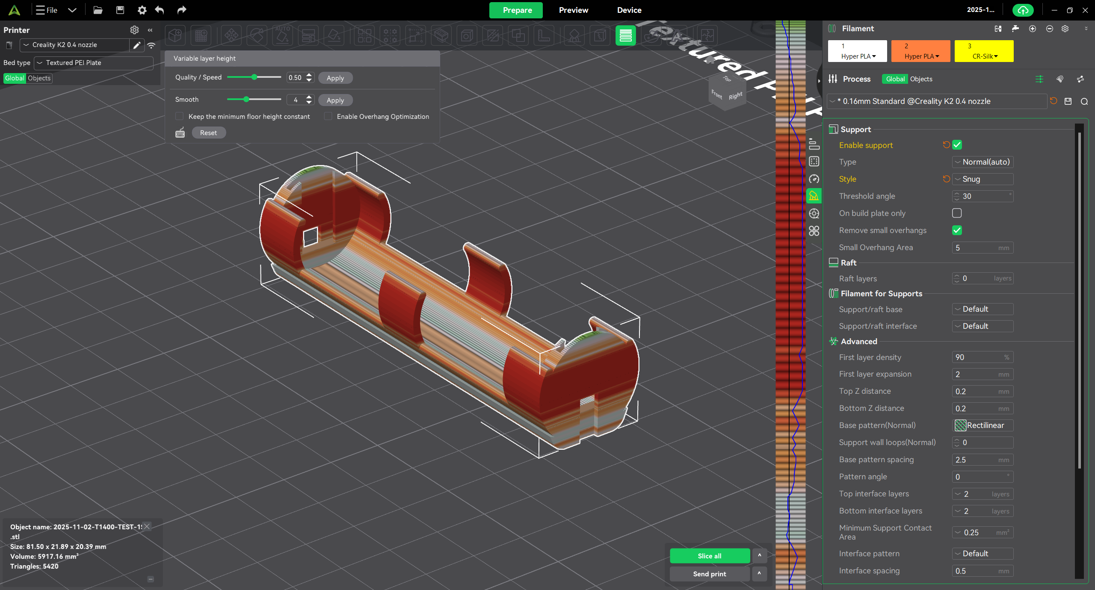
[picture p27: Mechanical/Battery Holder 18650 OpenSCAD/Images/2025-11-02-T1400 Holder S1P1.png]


First test, it's close. Fix:
- I did double spring that's not smart, I do have a button contact for the positive tab
- The center wing is too weak, I need to make it longer
- Ticker construction?

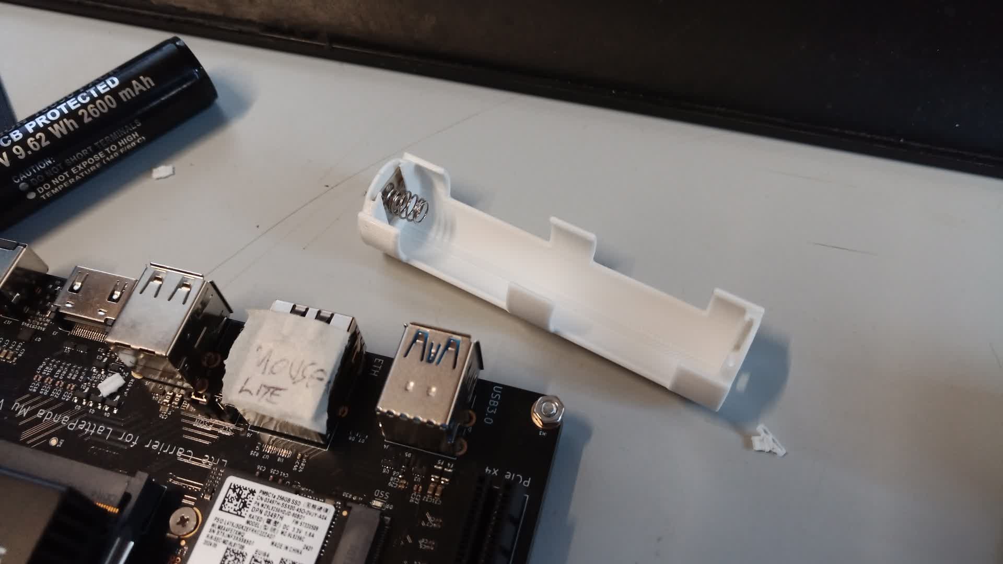
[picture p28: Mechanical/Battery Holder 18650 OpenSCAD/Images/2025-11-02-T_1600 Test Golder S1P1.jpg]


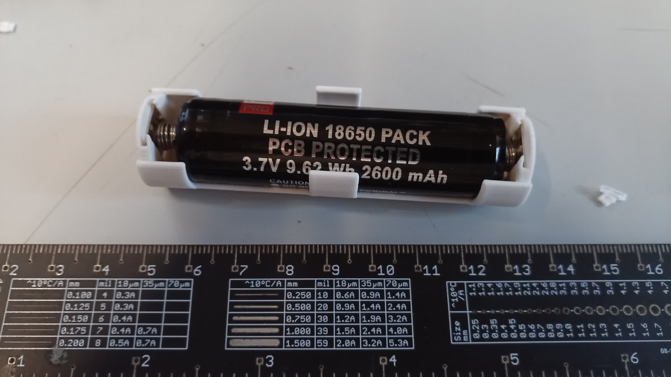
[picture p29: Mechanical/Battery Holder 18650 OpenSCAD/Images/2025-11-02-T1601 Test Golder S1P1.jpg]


## Holder 2S1P Dual Battery

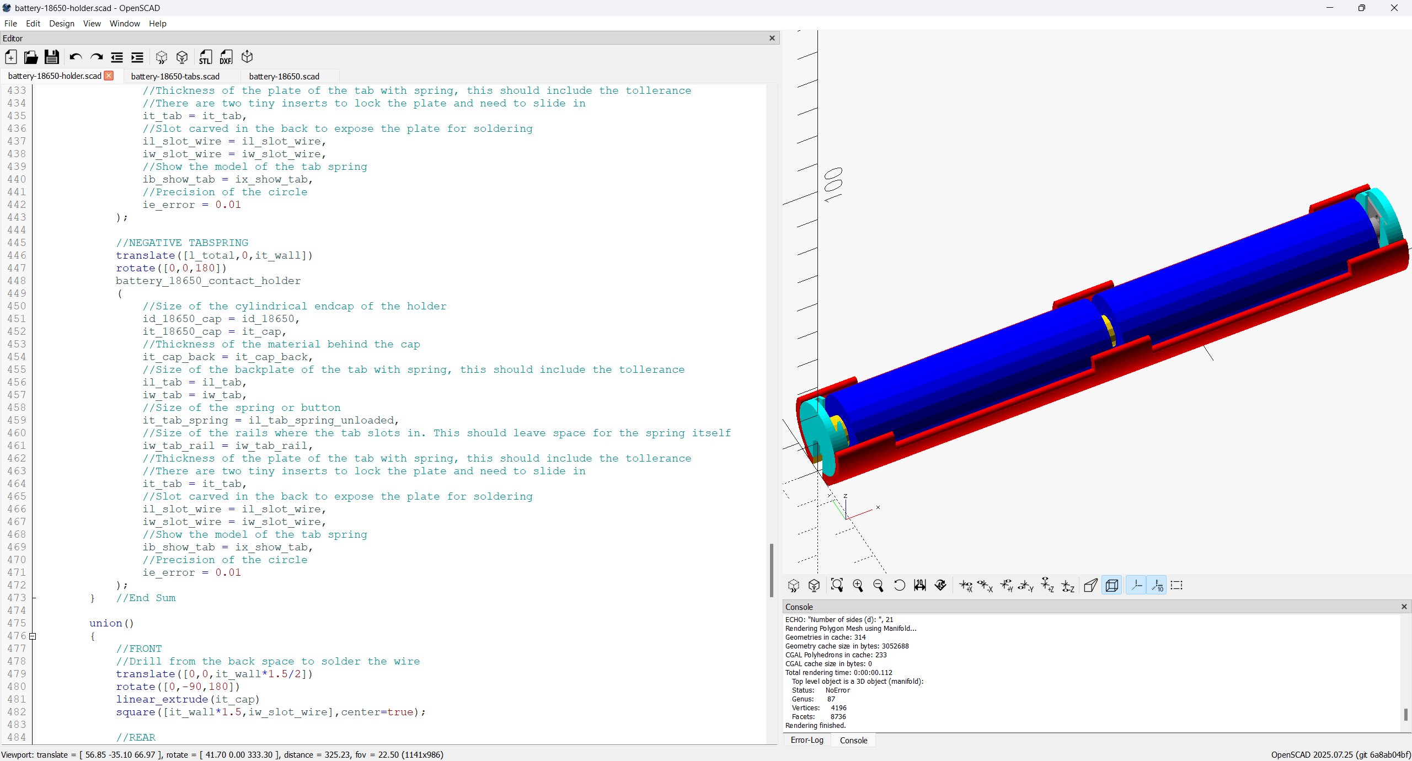
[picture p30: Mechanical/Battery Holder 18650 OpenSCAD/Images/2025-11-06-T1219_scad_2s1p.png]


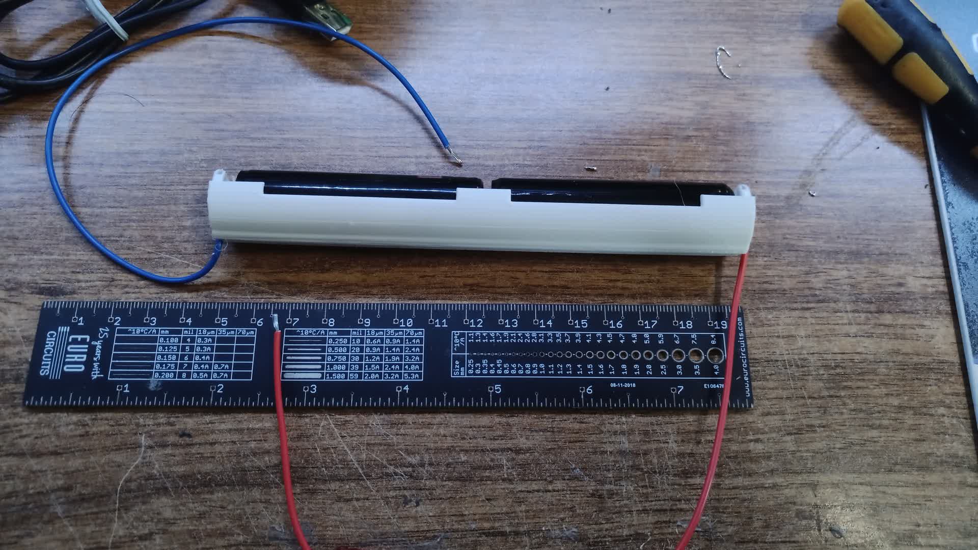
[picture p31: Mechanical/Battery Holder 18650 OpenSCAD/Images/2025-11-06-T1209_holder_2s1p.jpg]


## Holder 2S2P Quad Battery

3.7 * 4 = 14.8V nominal
4.2 * 4 = 16.8V max

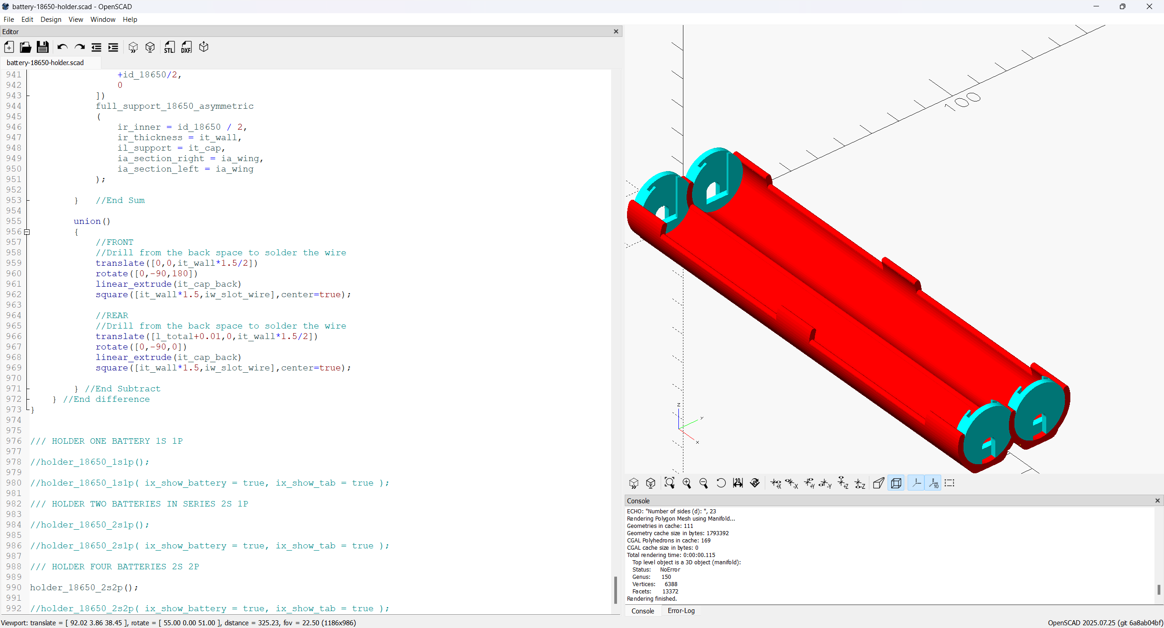
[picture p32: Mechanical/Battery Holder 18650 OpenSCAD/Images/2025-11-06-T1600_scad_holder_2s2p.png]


## Holder 2S2P Quad Battery Inverted

This is a fancy design, I did work to do the rounding to have an inverted holder.

Flanges have perfect tollerance.

TODO: I could tighten the spriing a little more, and I need to work better on holes for the wires. I could think of a lid? It holds well so it's not needed.

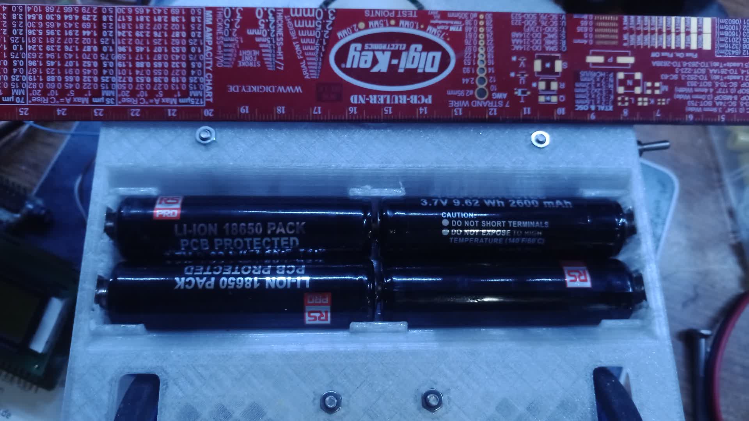
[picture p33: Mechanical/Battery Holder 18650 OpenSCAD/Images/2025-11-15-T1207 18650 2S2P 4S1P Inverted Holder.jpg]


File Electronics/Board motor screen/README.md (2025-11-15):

# Motor Board

This is a board that I designed in 2012 to control robots

It was convenient for me to use this board as I have a bounch of them assembled

It has an Atmel AT324PA PDIP40, an ISP programmer, power and breaks out all the pins

I also have a more recent board based on Atmel 4809 in SMD package, both work for this application.

## Gerber

### Bottom Side



### Top Side



### Top Components 



### Bot Components 



### Assembled Powered Flashed



## Adapters

For going to the board I soldered a number of adapters

### Adapter - Pinstrip to Eight Servo

TODO

### Adapter - Pinstrip to Screw COnnector

TODO

## BOM - Bill of Material

TODO

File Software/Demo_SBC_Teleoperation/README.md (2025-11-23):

# TELEOPERATION

Applications that use direct speed commands to pilot the robot

## CONSOLE TELEOPERATION

It's a python application that when wasd are pressed move the motor, no press motor stopped, q exit the application

It runs by going SSH into the robot

Keyboard library requires root permissions, so discarded, I can go without apparently, it's hacky but works





I tested and I can move the motors no issues.

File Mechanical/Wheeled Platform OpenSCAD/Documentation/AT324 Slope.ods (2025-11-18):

 |  | UPPER HOLE | 10.000 | distance of hole from start of slope
 |  | LOWER HOLE | 30.000
 |  |  | DEGREE | RADIANS | COS | SIN
 |  | ANGLE | 60.000 | 1.047 | 0.500 | 0.866
 |  | L | 50.000
 |  | H | 70.000
 |  | H_VERTICAL | 50.000 | how long it goes up vertically before sloping
 |  | TAN(ANGLE) | 1.732
 |  | H_SLOPE | 20.000
 | H_SLOPE*TAN(ANGLE) | L_SLOPE | 34.641
 |  | L_HORIZONTAL | 15.359
 |  |  | X (L) | Y (H)
 |  | Down left | 0.000 | 0.000
L |  | down right | 50.000 | 0.000
L | H | up right | 50.000 | 70.000
L_horizontal | H | up left | 34.641 | 70.000
L_horizontal-Dhole*sin(A) | H-Dhole*cos(A) | Upper hole | 25.981 | 65.000
L_horizontal / 2 | H_vertical+H_slope/2 | slope midpoint | 17.321 | 60.000
L_horizontal-Dhole*sin(A) | L_horizontal-Dhole*cos(A) | Lower hole | 8.660 | 55.000
 |  | vertical down | 0.000 | 50.000
 |  | CLOSE | 0.000 | 0.000
slope length | 40.000
i'm trying to find the exact coordinate where to drill
so the distance from the start of the slope is the anchor
it's a circle
so i use cos and sin with the angle

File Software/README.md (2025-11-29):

# INSTALL AND CONFIGURE SBC

## Luckfox PicoKVM

I always have trouble accessing SBC headless, I finally got a 49€ KVM to mitigate the issue and free myself from using discrete keyboard and mouse

[Luckfox PicoKVM Instructions](/Software/Luckfox%20PicoKVM)



## INSTALL UBUNTU

Install Ubuntu 24.04 Server LTS on the SBC and configure network and storage

[Ubuntu 24.04 Server Install Instructions](/Software/Ubuntu%2024_04%20server%20LTS)



### TTYS0 SSH PUTTY SERIAL

Configure the GRUB to use ttyS0 as UART serial interface to let the host connect via putty via USB to UART FTDI adapter

[TTYS0 SERIAL GRUB CONFIGURATION](/Software/ttys0%20SSH)



# SBC DEVELOPMENT

## VS Code Remote

Use VS code on host machine with remote SSH plugin to evelop and run code directly on the SBC via WiFi radio

[VS Code Remote Instructions](/Software/VS%20Code%20Remote%20Development%20on%20SBC)



## PYTHON - COMMUNICATE WITH ELECTRONICS

# OLLAMA

## Install Ollama

```
curl -fsSL https://ollama.com/install.sh | sh

ollama pull qwen3:4b

ollama pull qwen3:4b-instruct

ollama run qwen3:4b "What's the height of the Tour Eiffel in meters?" --verbose

ollama run qwen3:4b-instruct "What's the height of the Tour Eiffel in meters?" --verbose
```

[Qwen 3 4B Tool](https://ollama.com/library/qwen3:4b)

[Qwen 3 4B Vision Tool](https://ollama.com/library/qwen3-vl:4b)

<details>
  <summary>Ollama Install Log</summary>

```sh
sona@lpmu8gb:~$ curl -fsSL https://ollama.com/install.sh | sh
>>> Installing ollama to /usr/local
[sudo] password for sona:
>>> Downloading Linux amd64 bundle
######################################################################## 100.0%
>>> Creating ollama user...
>>> Adding ollama user to render group...
>>> Adding ollama user to video group...
>>> Adding current user to ollama group...
>>> Creating ollama systemd service...
>>> Enabling and starting ollama service...
Created symlink /etc/systemd/system/default.target.wants/ollama.service → /etc/systemd/system/ollama.service.
>>> The Ollama API is now available at 127.0.0.1:11434.
>>> Install complete. Run "ollama" from the command line.
WARNING: No NVIDIA/AMD GPU detected. Ollama will run in CPU-only mode.
  ```
  
</details>

<details>
  <summary>Ollama Run Inference</summary>

```sh
sona@lpmu8gb:~$ ollama run qwen3:4b-instructollama run qwen3:4b-instruct "What's the height of the Tour Eiffel in meters?" --verbose^C                                                                                              ollama run qwen3:4b-instruct "What's the height of the Tour Eiffel in meters?" --verbose the height of the Tour Eiffel in meters?" --verbose
The Eiffel Tower is 300 meters tall. This includes the tower structure and
the antenna on top. The original structure of the tower is about 300
meters tall, but the total height with the antenna is approximately 330
meters. However, the commonly cited height of the Eiffel Tower is **300
meters** when referring to the main structure, and **330 meters** when
including the antenna.

So, to clarify:

- **Height of the Eiffel Tower (main structure)**: **300 meters**
- **Total height (including antenna)**: **330 meters**

Therefore, the height of the Eiffel Tower is typically stated as **300
meters** for the tower itself. ✅

total duration:       18.293521648s
load duration:        97.885315ms
prompt eval count:    21 token(s)
prompt eval duration: 1.346030951s
prompt eval rate:     15.60 tokens/s
eval count:           160 token(s)
eval duration:        16.774703785s
eval rate:            9.54 tokens/s
  ```
  
</details>

<details>
  <summary>HTOP Durin Ollama</summary>

```sh
    0[###########################97.3%] Tasks: 47, 132 thr, 105 kthr; 4 runnin
    1[###########################99.3%] Load average: 1.95 0.57 0.39
    2[###########################99.3%] Uptime: 07:20:04
    3[###########################96.7%]
  Mem[|||||||||||||||||#@$$3.94G/7.47G]
  Swp[|#                    756K/4.00G]

  [Main] [I/O]
    PID USER       PRI  NI  VIRT   RES   SHR S  CPU%▽MEM%   TIME+  Command
   6322 ollama      20   0 5241M 3362M 25216 S  46.4 44.0  0:09.44 /usr/local/bi
   6325 ollama      20   0 5241M 3362M 25216 R  30.5 44.0  0:01.09 /usr/local/bi
   6324 ollama      20   0 5241M 3362M 25216 S  22.5 44.0  0:06.79 /usr/local/bi
   7353 ollama      20   0 5241M 3362M 25216 R   6.0 44.0  0:00.09 /usr/local/bi
   7352 ollama      20   0 5241M 3362M 25216 R   5.3 44.0  0:00.08 /usr/local/bi
   7354 ollama      20   0 5241M 3362M 25216 R   5.3 44.0  0:00.08 /usr/local/bi
   7068 sona        20   0  8348  4608  3712 R   1.3  0.1  0:00.09 htop
   5544 sona        20   0 1329M 77564 48896 S   0.7  1.0  0:02.18 /home/sona/.v
   5715 sona        20   0 31.8G  145M 56576 S   0.7  1.9  0:04.04 /home/sona/.v
   6329 ollama      20   0 5241M 3362M 25216 S   0.7 44.0  0:10.99 /usr/local/bi
      1 root        20   0 22748 13220  9124 S   0.0  0.2  0:04.41 /sbin/init
    325 root        19  -1 50504 16100 15076 S   0.0  0.2  0:00.63 /usr/lib/syst
    382 root        RT   0  282M 27008  8576 S   0.0  0.3  0:00.87 /sbin/multipa
F1Help  F2Setup F3SearchF4FilterF5Tree  F6SortByF7Nice -F8Nice +F9Kill  F10Quit
  ```
  
</details>

```python
#!/usr/bin/env python3
"""
Interface with Ollama using qwen3:4b-instruct

This script:
- Launches Ollama as a subprocess
- Queries the qwen3:4b-instruct model
- Cleans up by terminating Ollama when the script exits

Requirements:
- Ollama installed locally
- qwen3:4b-instruct pulled via `ollama pull qwen3:4b-instruct`
- Python 3.12+ with requests installed (`pip install requests`)
"""

import subprocess
import requests
import time
import atexit
import sys

OLLAMA_API_URL = "http://localhost:11434/api/generate"
MODEL_NAME = "qwen3:4b-instruct"

ollama_process = None

def start_ollama():
    """Start Ollama server as a subprocess."""
    global ollama_process
    try:
        ollama_process = subprocess.Popen(
            ["ollama", "serve"],
            stdout=subprocess.PIPE,
            stderr=subprocess.PIPE
        )
        # Give Ollama a moment to spin up
        time.sleep(2)
        print("✅ Ollama server started.")
    except Exception as e:
        print(f"Failed to start Ollama: {e}")
        sys.exit(1)

def stop_ollama():
    """Terminate Ollama subprocess cleanly."""
    global ollama_process
    if ollama_process:
        ollama_process.terminate()
        try:
            ollama_process.wait(timeout=5)
        except subprocess.TimeoutExpired:
            ollama_process.kill()
        print("🛑 Ollama server stopped.")

def query_ollama(prompt: str) -> str:
    """Send a prompt to Ollama and return the model's response."""
    payload = {
        "model": MODEL_NAME,
        "prompt": prompt,
        "stream": False
    }
    try:
        response = requests.post(OLLAMA_API_URL, json=payload)
        response.raise_for_status()
        data = response.json()
        return data.get("response", "")
    except requests.exceptions.RequestException as e:
        return f"Error communicating with Ollama: {e}"

def main():
    start_ollama()
    atexit.register(stop_ollama)  # ensure cleanup on exit

    user_prompt = "Explain the difference between supervised and unsupervised learning."
    print(f"Querying {MODEL_NAME}...\n")
    answer = query_ollama(user_prompt)
    print("Response:\n", answer)

if __name__ == "__main__":
    main()

```

<details>
  <summary>PYTHON SCRIPT</summary>

```sh
uv run demo_ollama.py 
Using CPython 3.14.0
Creating virtual environment at: .venv
Installed 5 packages in 12ms
✅ Ollama server started.
Querying qwen3:4b-instruct...

Response:
 Certainly! The main difference between **supervised** and **unsupervised learning** lies in how the data is structured and how the model is trained.

---

### 🔹 Supervised Learning

**Definition:**  
In supervised learning, the model is trained on labeled data — that is, data where each input is paired with a known output or target.

**How it works:**  
The algorithm learns a mapping from inputs to outputs by observing examples of input-output pairs. Once trained, it can make predictions on new, unseen data.

**Example:**  
Predicting house prices based on features like size, location, number of bedrooms, etc.  
- Input: Size, location, number of bedrooms  
- Output: Price (known and labeled)

**Common Algorithms:**  
- Linear Regression  
- Decision Trees  
- Support Vector Machines (SVM)  
- Neural Networks  

**Use Cases:**  
- Classification (e.g., spam detection)  
- Regression (e.g., predicting sales)

---

### 🔹 Unsupervised Learning

**Definition:**  
In unsupervised learning, the model is trained on data without labeled outputs. The algorithm must find patterns, structures, or relationships in the data on its own.

**How it works:**  
There is no target variable to learn. Instead, the model discovers hidden patterns, groupings, or dimensions in the data.

**Example:**  
Clustering customers into groups based on purchasing behavior.  
- Input: Purchase history  
- Output: No known label — the model discovers natural groupings

**Common Algorithms:**  
- K-Means Clustering  
- Principal Component Analysis (PCA)  
- Hierarchical Clustering  
- Autoencoders  

**Use Cases:**  
- Customer segmentation  
- Anomaly detection  
- Dimensionality reduction  
- Data compression

---

### 🔍 Key Difference Summary:

| Feature                     | Supervised Learning                        | Unsupervised Learning                     |
|---------------------------|--------------------------------------------|------------------------------------------|
| Labeled data?             | Yes (input-output pairs)                  | No (only inputs)                        |
| Goal                      | Predict known outputs                    | Discover hidden patterns or structure  |
| Training objective        | Minimize prediction error              | Maximize data structure discovery      |
| Example use               | Spam detection, price prediction       | Customer segmentation, anomaly detection |

---

### 📝 In short:
- **Supervised learning** is like teaching a student with correct answers — you show them a question and the right answer, and they learn to respond correctly.
- **Unsupervised learning** is like letting a student explore a room without being told what's in it — they discover patterns and groupings on their own.

Both are essential in machine learning and are used depending on the nature of the problem and the availability of labeled data.
🛑 Ollama server stopped.
  ```
  
</details>

## (OLD) CONFIGURE NETWORK

For reasons I do not understand the network interfaces change name and stop working...

Powered



I had to plug screen and keyboard



The trick is to add a line to ```/etc/netplan/50-cloud-init.yaml```

```
sona@lpn10016gb:~$ ip a
1: lo: <LOOPBACK,UP,LOWER_UP> mtu 65536 qdisc noqueue state UNKNOWN group defaul                                                    t qlen 1000
    link/loopback 00:00:00:00:00:00 brd 00:00:00:00:00:00
    inet 127.0.0.1/8 scope host lo
       valid_lft forever preferred_lft forever
    inet6 ::1/128 scope host noprefixroute
       valid_lft forever preferred_lft forever
2: enp3s0: <BROADCAST,MULTICAST,UP,LOWER_UP> mtu 1500 qdisc fq_codel state UP gr                                                    oup default qlen 1000
    link/ether d2:f7:f7:c0:0c:13 brd ff:ff:ff:ff:ff:ff
    inet 192.168.1.240/23 metric 100 brd 192.168.1.255 scope global dynamic enp3                                                    s0
       valid_lft 99850sec preferred_lft 99850sec
    inet6 fe80::d0f7:f7ff:fec0:c13/64 scope link
       valid_lft forever preferred_lft forever
3: wlp2s0: <BROADCAST,MULTICAST> mtu 1500 qdisc noop state DOWN group default ql                                                    en 1000
    link/ether 10:b1:df:bd:b3:b9 brd ff:ff:ff:ff:ff:ff
sona@lpn10016gb:~$ sudo cat /etc/netplan/50-cloud-init.yaml
[sudo] password for sona:
network:
  version: 2
  ethernets:
    enp3s0:
      dhcp4: true
```

# CONFIGURE WIFI

```
sona@lpn10016gb:~$ ip a
1: lo: <LOOPBACK,UP,LOWER_UP> mtu 65536 qdisc noqueue state UNKNOWN group default qlen 1000
    link/loopback 00:00:00:00:00:00 brd 00:00:00:00:00:00
    inet 127.0.0.1/8 scope host lo
       valid_lft forever preferred_lft forever
    inet6 ::1/128 scope host noprefixroute
       valid_lft forever preferred_lft forever
2: enp3s0: <BROADCAST,MULTICAST,UP,LOWER_UP> mtu 1500 qdisc fq_codel state UP group default qlen 1000
    link/ether d2:f7:f7:c0:0c:13 brd ff:ff:ff:ff:ff:ff
    inet 192.168.1.240/23 metric 100 brd 192.168.1.255 scope global dynamic enp3s0
       valid_lft 97509sec preferred_lft 97509sec
    inet6 fe80::d0f7:f7ff:fec0:c13/64 scope link
       valid_lft forever preferred_lft forever
3: wlp2s0: <BROADCAST,MULTICAST> mtu 1500 qdisc noop state DOWN group default qlen 1000
    link/ether 10:b1:df:bd:b3:b9 brd ff:ff:ff:ff:ff:ff
sona@lpn10016gb:~$ ^C
sona@lpn10016gb:~$ ls
test_microphone
sona@lpn10016gb:~$ ^C
sona@lpn10016gb:~$ sudo nano /etc/netplan/50-cloud-init.yaml
[sudo] password for sona:
sona@lpn10016gb:~$ sudo cat /etc/netplan/50-cloud-init.yaml
network:
  version: 2
  ethernets:
    enp3s0:
      dhcp4: true
  wifis:
    wlp2s0:
      dhcp4: true
      access-points:
        "xxx":
          password: "yyy"
```

Doesn't work, so I search for debug

```
sudo netplan --debug generate

```

Apply without rebooting

```
sudo netplan apply
sudo systemctl restart NetworkManager
```

Of course it bricked the network -.-

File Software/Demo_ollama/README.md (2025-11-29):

# MCP tool to send trajectory

```
sona@lpmu8gb:~/Demo_ollama$ uv run demo_gradio6_robot_mcp.py 
✅ Ollama server started.
Failed to open serial port: name 'serial' is not defined
* Running on local URL:  http://0.0.0.0:7860
* To create a public link, set `share=True` in `launch()`.
➡️ Sent: ```
➡️ Sent: VT25R-5L+5/0
➡️ Sent: VT10R+5L+5/0
➡️ Sent: VT23R+5L-5/0
➡️ Sent: VT12R+2L+3/0
➡️ Sent: ```
➡️ Sent: ```
➡️ Sent: VT20R+5L+5/0
➡️ Sent: VT15R+3L+3/0
➡️ Sent: VT10R+1L+1/0
➡️ Sent: VT15R-1L-1/0
➡️ Sent: VT20R-3L-3/0
➡️ Sent: VT25R-5L-5/0
➡️ Sent: ```
```

I did it, now LLM generates the correct commands to send to the electronics

Had to do a reparsing because python is dumb and cannot not reencode the terminator

```
uv run demo_gradio6_robot_mcp_serial.py 
✅ Ollama server started.
* Running on local URL:  http://0.0.0.0:7860
* To create a public link, set `share=True` in `launch()`.
❌ Failed to parse: ```
➡️ Sent: b'VT25R5L5\x00'
➡️ Sent: b'VT10R5L5\x00'
➡️ Sent: b'VT23R5L-5\x00'
➡️ Sent: b'VT12R2L3\x00'
➡️ Sent: b'VT20R-3L2\x00'
➡️ Sent: b'VT15R4L-4\x00'
➡️ Sent: b'VT25R5L5\x00'
❌ Failed to parse: ```
^CKeyboard interruption in main thread... closing server.
🛑 Ollama server stopped.
```

# LLamaindex

added dependencies

```
[project]
name = "ollama-qwen"
version = "0.1.0"
description = "Python interface to Ollama using qwen3:4b-instruct"
readme = "README.md"
requires-python = ">=3.12"

dependencies = [
    "requests>=2.32",
    "gradio>=6.0",
    "pyserial",
    "llama-index-core",
    "llama-index-llms-ollama>=0.9.0",
    "llama-index-embeddings-openai>=0.5.1",
]
```

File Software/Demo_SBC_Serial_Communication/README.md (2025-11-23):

# PYTHON

This section is about demos to interface the SBC with the AT324 and test serial communication and commands

## Serial Ports

The Latte Panda Mu and the Lite Carrier boards have a number of serial interfaces

I need to find out how they are mapped to linux ubuntu and how to use them

## Dev Tree

ttySxxx should be serial interfaces, on the pi they are also mapped to ttyAMAxxx

```
sona@sona-lp-n100-8gb:~$ ls /dev/
autofs           i2c-7         nvme0     tty24  tty59      ttyS6
block            i2c-8         nvme0n1   tty25  tty6       ttyS7
btrfs-control    i2c-9         nvram     tty26  tty60      ttyS8
bus              initctl       port      tty27  tty61      ttyS9
char             input         ppp       tty28  tty62      udmabuf
console          kmsg          psaux     tty29  tty63      uhid
core             kvm           ptmx      tty3   tty7       uinput
cpu              log           pts       tty30  tty8       urandom
cpu_dma_latency  loop0         random    tty31  tty9       userfaultfd
cuse             loop1         rfkill    tty32  ttyprintk  userio
disk             loop10        rtc       tty33  ttyS0      vcs
dma_heap         loop11        rtc0      tty34  ttyS1      vcs1
dri              loop2         shm       tty35  ttyS10     vcs2
drm_dp_aux0      loop3         snapshot  tty36  ttyS11     vcs3
ecryptfs         loop4         snd       tty37  ttyS12     vcs4
fb0              loop5         stderr    tty38  ttyS13     vcs5
fd               loop6         stdin     tty39  ttyS14     vcs6
full             loop7         stdout    tty4   ttyS15     vcsa
fuse             loop8         tpm0      tty40  ttyS16     vcsa1
gpiochip0        loop9         tpmrm0    tty41  ttyS17     vcsa2
hidraw0          loop-control  tty       tty42  ttyS18     vcsa3
hidraw1          mapper        tty0      tty43  ttyS19     vcsa4
hpet             mcelog        tty1      tty44  ttyS2      vcsa5
hugepages        mei0          tty10     tty45  ttyS20     vcsa6
hwrng            mem           tty11     tty46  ttyS21     vcsu
i2c-0            mmcblk0       tty12     tty47  ttyS22     vcsu1
i2c-1            mmcblk0boot0  tty13     tty48  ttyS23     vcsu2
i2c-10           mmcblk0boot1  tty14     tty49  ttyS24     vcsu3
i2c-11           mmcblk0p1     tty15     tty5   ttyS25     vcsu4
i2c-12           mmcblk0p2     tty16     tty50  ttyS26     vcsu5
i2c-13           mmcblk0rpmb   tty17     tty51  ttyS27     vcsu6
i2c-14           mqueue        tty18     tty52  ttyS28     vfio
i2c-15           mtd           tty19     tty53  ttyS29     vga_arbiter
i2c-2            mtd0          tty2      tty54  ttyS3      vhci
i2c-3            mtd0ro        tty20     tty55  ttyS30     vhost-net
i2c-4            net           tty21     tty56  ttyS31     vhost-vsock
i2c-5            ng0n1         tty22     tty57  ttyS4      zero
i2c-6            null          tty23     tty58  ttyS5      zfs
```

## UBUNTU SERIAL PORT PERMISSION

The library is ```pyserial``` if you try to access ports on Linux it will fail

```
Failed to open /dev/ttyS4: [Errno 13] could not open port /dev/ttyS4: [Errno 13] Permission denied: '/dev/ttyS4'
```

You need to give permission from your USER to the ports.

Commands let you see what the premission group is

Ubuntu Desktop

```
PermissionError: [Errno 13] Permission denied: '/dev/ttyS1'

sona@sona-lp-n100-8gb:~$ ls -l /dev/ttyS0
crw-rw---- 1 root dialout 4, 64 Sep 21 09:09 /dev/ttyS0
```

Ubuntu Server

```
sona@lpmu8gb:~$ ls -l /dev/ttyS0
crw------- 1 sona tty 4, 64 Nov 23 11:11 /dev/ttyS0
```

Permission for those ports is group dialout, so I add those permissions to my user

```
sudo usermod -a -G dialout $USER
sudo reboot
```

With that access to ports from user is allowed.

Remember that ```/dev/ttyS0``` is the port that Ubuntu uses for the serial console

## SERIAL PORT SPEED (Windows vs Linux)

Under windows I'm free to give the baud rate I want, I tested 250Kb/s.

Under Linux it behaves differently. There seems to be a discretization of baud for no good reasons. I know the Intel hardware can do 250Kb/s under windows, but under Linux if I request that it does 9600 b/s.



I need to request likely from this table I found in pyserial for posix.

Right now I selected 115200b/s on Linux



```
#serialposix.py:96
BAUDRATE_CONSTANTS = {
            0:       0o000000,  # hang up
            50:      0o000001,
            75:      0o000002,
            110:     0o000003,
            134:     0o000004,
            150:     0o000005,
            200:     0o000006,
            300:     0o000007,
            600:     0o000010,
            1200:    0o000011,
            1800:    0o000012,
            2400:    0o000013,
            4800:    0o000014,
            9600:    0o000015,
            19200:   0o000016,
            38400:   0o000017,
            57600:   0o010001,
            115200:  0o010002,
            230400:  0o010003,
            460800:  0o010004,
            500000:  0o010005,
            576000:  0o010006,
            921600:  0o010007,
            1000000: 0o010010,
            1152000: 0o010011,
            1500000: 0o010012,
            2000000: 0o010013,
            2500000: 0o010014,
            3000000: 0o010015,
            3500000: 0o010016,
            4000000: 0o010017
        }
```

There is an issue with speed on the microcontroller, there I do have coarser discretization because of clock speed and UART hadware, I can select 113636 and it is compatible with 115200.

```
//56818
//#define UART_UBRR			23

//113636
#define UART_UBRR			10

//125000
//#define UART_UBRR			9

//138888
//#define UART_UBRR			8

//156 250
//#define UART_UBRR			7

//250 000 	
//#define UART_UBRR			4
```

It's 20MHz / 16 / (UBRR+1). There is a fast mode, setting the prescaler to 8, but it halves the sampling and can result in more errors.

I'll need to go faster for the final application, targeting 500Kb/s.

## LOOPBACK JUMPER

A trick to test the SBC communication is to do a jumper and do loopback, so it removes the speed mismatch. It's useful to debug if the problem is in software, in this case it wasn't.



## UV VENV

Install virtual environment for python

```
sudo snap install astral-uv --classic
```

```
sona@lpmu8gb:~/Demo 2 - Serial Communication SBC$ sudo snap install astral-uv --classic
2025-11-23T09:38:36Z INFO
Waiting for automatic snapd
restart...
astral-uv 0.9.5 from Alex Lowe (lengau) installed
```

## Create folder

Make sure you create a folder for the pythoin demos to run

```
sudo mkdir demo_serial_communication
cd demo_serial_communication
```

TODO: How do I clone just some of the code? Perhaps I do a release?

## UV TOML 

The most convenient way for it to autogenerate the virtual environment is to generate a toml project file and run uv with the command ```uv run```

This will make sure that with a single line a venv is created with the right python version and dependencies

```pyproject.toml```

```python
[project]
name = "demo_serial_communication_sbc_electronics"
version = "0.1.0"
requires-python = ">=3.13"
dependencies = [
    "pyserial",
]
```

## DEMO 1 - ENUMERATE SERIAL PORTS

Now, the first application tests the ports enumerated in /dev that are serial ports

```demo_1_enumerate_serial.py```

```
import serial
print(serial.__file__)

import serial.tools.list_ports

ports = serial.tools.list_ports.comports()
for port in ports:
    print(port.device)
```

Execute the script

```
uv run demo_1_enumerate_serial.py 
```

The first run will create ```.venv``` with the local libraries and interpreter and execute. In this screen I displayed the location of the library to make sure it's executing from .venv

```
uv run demo_1_enumerate_serial.py 
Using CPython 3.14.0
Creating virtual environment at: .venv
Installed 1 package in 16ms
/home/sona/Demo 2 - Serial Communication SBC/.venv/lib/python3.14/site-packages/serial/__init__.py
/dev/ttyS31
/dev/ttyS30
/dev/ttyS29
/dev/ttyS28
/dev/ttyS27
/dev/ttyS26
/dev/ttyS25
/dev/ttyS24
/dev/ttyS23
/dev/ttyS22
/dev/ttyS21
/dev/ttyS20
/dev/ttyS19
/dev/ttyS18
/dev/ttyS17
/dev/ttyS16
/dev/ttyS15
/dev/ttyS14
/dev/ttyS13
/dev/ttyS12
/dev/ttyS11
/dev/ttyS10
/dev/ttyS9
/dev/ttyS8
/dev/ttyS7
/dev/ttyS3
/dev/ttyS2
/dev/ttyS1
/dev/ttyS6
/dev/ttyS5
/dev/ttyS4
/dev/ttyS0
```

In the Latte Panda Mu Lite Board, serial port S0 is the debug interface that is connected by GRUB to the linux serial terminal

[Linux Grub TTYS0 Instructions](/Software/ttys0%20SSH)

While S4 to S6 are three serial ports available to user, I diagnosed them with an oscilloscope and terminal to make sure they work

TODO: add documentation for the serial ports here?

## DEMO 2 - PORT SCAN

```
uv run demo_2_ask_signature.py 
```

Output if user lacks permission for dialout

```
$ uv run demo_2_ask_signature.py 
/home/sona/Demo 2 - Serial Communication SBC/demo_2_ask_signature.py:18: SyntaxWarning: "\D" is an invalid escape sequence. Such sequences will not work in the future. Did you mean "\\D"? A raw string is also an option.
  (ToB) F:\Data\Project\Project OrangeBot\RAMIE-RAD_AI_Messing_In_Earthworks\Software\Demo 1 - Serial Communication>python demo_2_ask_signature.py
Failed to open /dev/ttyS31: [Errno 13] could not open port /dev/ttyS31: [Errno 13] Permission denied: '/dev/ttyS31'
Failed to open /dev/ttyS30: [Errno 13] could not open port /dev/ttyS30: [Errno 13] Permission denied: '/dev/ttyS30'
Failed to open /dev/ttyS29: [Errno 13] could not open port /dev/ttyS29: [Errno 13] Permission denied: '/dev/ttyS29'
Failed to open /dev/ttyS28: [Errno 13] could not open port /dev/ttyS28: [Errno 13] Permission denied: '/dev/ttyS28'
Failed to open /dev/ttyS27: [Errno 13] could not open port /dev/ttyS27: [Errno 13] Permission denied: '/dev/ttyS27'
Failed to open /dev/ttyS26: [Errno 13] could not open port /dev/ttyS26: [Errno 13] Permission denied: '/dev/ttyS26'
Failed to open /dev/ttyS25: [Errno 13] could not open port /dev/ttyS25: [Errno 13] Permission denied: '/dev/ttyS25'
Failed to open /dev/ttyS24: [Errno 13] could not open port /dev/ttyS24: [Errno 13] Permission denied: '/dev/ttyS24'
Failed to open /dev/ttyS23: [Errno 13] could not open port /dev/ttyS23: [Errno 13] Permission denied: '/dev/ttyS23'
Failed to open /dev/ttyS22: [Errno 13] could not open port /dev/ttyS22: [Errno 13] Permission denied: '/dev/ttyS22'
Failed to open /dev/ttyS21: [Errno 13] could not open port /dev/ttyS21: [Errno 13] Permission denied: '/dev/ttyS21'
Failed to open /dev/ttyS20: [Errno 13] could not open port /dev/ttyS20: [Errno 13] Permission denied: '/dev/ttyS20'
Failed to open /dev/ttyS19: [Errno 13] could not open port /dev/ttyS19: [Errno 13] Permission denied: '/dev/ttyS19'
Failed to open /dev/ttyS18: [Errno 13] could not open port /dev/ttyS18: [Errno 13] Permission denied: '/dev/ttyS18'
Failed to open /dev/ttyS17: [Errno 13] could not open port /dev/ttyS17: [Errno 13] Permission denied: '/dev/ttyS17'
Failed to open /dev/ttyS16: [Errno 13] could not open port /dev/ttyS16: [Errno 13] Permission denied: '/dev/ttyS16'
Failed to open /dev/ttyS15: [Errno 13] could not open port /dev/ttyS15: [Errno 13] Permission denied: '/dev/ttyS15'
Failed to open /dev/ttyS14: [Errno 13] could not open port /dev/ttyS14: [Errno 13] Permission denied: '/dev/ttyS14'
Failed to open /dev/ttyS13: [Errno 13] could not open port /dev/ttyS13: [Errno 13] Permission denied: '/dev/ttyS13'
Failed to open /dev/ttyS12: [Errno 13] could not open port /dev/ttyS12: [Errno 13] Permission denied: '/dev/ttyS12'
Failed to open /dev/ttyS11: [Errno 13] could not open port /dev/ttyS11: [Errno 13] Permission denied: '/dev/ttyS11'
Failed to open /dev/ttyS10: [Errno 13] could not open port /dev/ttyS10: [Errno 13] Permission denied: '/dev/ttyS10'
Failed to open /dev/ttyS9: [Errno 13] could not open port /dev/ttyS9: [Errno 13] Permission denied: '/dev/ttyS9'
Failed to open /dev/ttyS8: [Errno 13] could not open port /dev/ttyS8: [Errno 13] Permission denied: '/dev/ttyS8'
Failed to open /dev/ttyS7: [Errno 13] could not open port /dev/ttyS7: [Errno 13] Permission denied: '/dev/ttyS7'
Failed to open /dev/ttyS3: [Errno 13] could not open port /dev/ttyS3: [Errno 13] Permission denied: '/dev/ttyS3'
Failed to open /dev/ttyS2: [Errno 13] could not open port /dev/ttyS2: [Errno 13] Permission denied: '/dev/ttyS2'
Failed to open /dev/ttyS1: [Errno 13] could not open port /dev/ttyS1: [Errno 13] Permission denied: '/dev/ttyS1'
Failed to open /dev/ttyS6: [Errno 13] could not open port /dev/ttyS6: [Errno 13] Permission denied: '/dev/ttyS6'
Failed to open /dev/ttyS5: [Errno 13] could not open port /dev/ttyS5: [Errno 13] Permission denied: '/dev/ttyS5'
Failed to open /dev/ttyS4: [Errno 13] could not open port /dev/ttyS4: [Errno 13] Permission denied: '/dev/ttyS4'
Testing port: /dev/ttyS0
```

Output if user has permission for dialout, but I had a problem of not receiving

```
sona@lpmu8gb:~$ cd Demo\ 2\ -\ Serial\ Communication\ SBC/
sona@lpmu8gb:~/Demo 2 - Serial Communication SBC$ uv run demo_2_ask_signature.py 
/home/sona/Demo 2 - Serial Communication SBC/demo_2_ask_signature.py:18: SyntaxWarning: "\D" is an invalid escape sequence. Such sequences will not work in the future. Did you mean "\\D"? A raw string is also an option.
  (ToB) F:\Data\Project\Project OrangeBot\RAMIE-RAD_AI_Messing_In_Earthworks\Software\Demo 1 - Serial Communication>python demo_2_ask_signature.py
Failed to open /dev/ttyS31: Could not configure port: (5, 'Input/output error')
Failed to open /dev/ttyS30: Could not configure port: (5, 'Input/output error')
Failed to open /dev/ttyS29: Could not configure port: (5, 'Input/output error')
Failed to open /dev/ttyS28: Could not configure port: (5, 'Input/output error')
Failed to open /dev/ttyS27: Could not configure port: (5, 'Input/output error')
Failed to open /dev/ttyS26: Could not configure port: (5, 'Input/output error')
Failed to open /dev/ttyS25: Could not configure port: (5, 'Input/output error')
Failed to open /dev/ttyS24: Could not configure port: (5, 'Input/output error')
Failed to open /dev/ttyS23: Could not configure port: (5, 'Input/output error')
Failed to open /dev/ttyS22: Could not configure port: (5, 'Input/output error')
Failed to open /dev/ttyS21: Could not configure port: (5, 'Input/output error')
Failed to open /dev/ttyS20: Could not configure port: (5, 'Input/output error')
Failed to open /dev/ttyS19: Could not configure port: (5, 'Input/output error')
Failed to open /dev/ttyS18: Could not configure port: (5, 'Input/output error')
Failed to open /dev/ttyS17: Could not configure port: (5, 'Input/output error')
Failed to open /dev/ttyS16: Could not configure port: (5, 'Input/output error')
Failed to open /dev/ttyS15: Could not configure port: (5, 'Input/output error')
Failed to open /dev/ttyS14: Could not configure port: (5, 'Input/output error')
Failed to open /dev/ttyS13: Could not configure port: (5, 'Input/output error')
Failed to open /dev/ttyS12: Could not configure port: (5, 'Input/output error')
Failed to open /dev/ttyS11: Could not configure port: (5, 'Input/output error')
Failed to open /dev/ttyS10: Could not configure port: (5, 'Input/output error')
Failed to open /dev/ttyS9: Could not configure port: (5, 'Input/output error')
Failed to open /dev/ttyS8: Could not configure port: (5, 'Input/output error')
Failed to open /dev/ttyS7: Could not configure port: (5, 'Input/output error')
Failed to open /dev/ttyS3: Could not configure port: (5, 'Input/output error')
Failed to open /dev/ttyS2: Could not configure port: (5, 'Input/output error')
Failed to open /dev/ttyS1: Could not configure port: (5, 'Input/output error')
Testing port: /dev/ttyS6
Testing port: /dev/ttyS5
Testing port: /dev/ttyS4
Testing port: /dev/ttyS0
```

## DEMO 3 - CONTINUOUS TRANSMISSION

I closed the cable with a jumper to test problems, no problems. It turns out it was speed under linux.

```
Response from /dev/ttyS4: b'SIGN\x00'
Testing port: /dev/ttyS4
Response from /dev/ttyS4: b'SIGN\x00'
Testing port: /dev/ttyS4
Response from /dev/ttyS4: b'SIGN\x00'
Testing port: /dev/ttyS4
Response from /dev/ttyS4: b'SIGN\x00'
Testing port: /dev/ttyS4
Response from /dev/ttyS4: b'SIGN\x00'
Testing port: /dev/ttyS4
Response from /dev/ttyS4: b'SIGN\x00'
Testing port: /dev/ttyS4
Response from /dev/ttyS4: b'SIGN\x00'
Testing port: /dev/ttyS4
Response from /dev/ttyS4: b'SIGN\x00'
Testing port: /dev/ttyS4
Response from /dev/ttyS4: b'SIGN\x00'
Testing port: /dev/ttyS4
```

Connected the electronics

I moved application to 115200 b/s
I moved the firmware to 113636 b/s
Now it communicates fine.
I'll need to significantly accelerate the communication for the future

```
esting port: /dev/ttyS4
Response from /dev/ttyS4: b'RAMIE\x00'
Testing port: /dev/ttyS4
Response from /dev/ttyS4: b'RAMIE\x00'
Testing port: /dev/ttyS4
Response from /dev/ttyS4: b'RAMIE\x00'
Testing port: /dev/ttyS4
```

# DEMO 4 - Direct speed

Works really well, it finds a serial port that answer with something, and uses that to communicate with the board

```
sona@lpmu8gb:~/Demo 2 - Serial Communication SBC$ uv run demo_4_serial_direct_speed.py 
Failed to open /dev/ttyS31: Could not configure port: (5, 'Input/output error')
Failed to open /dev/ttyS30: Could not configure port: (5, 'Input/output error')
Failed to open /dev/ttyS29: Could not configure port: (5, 'Input/output error')
Failed to open /dev/ttyS28: Could not configure port: (5, 'Input/output error')
Failed to open /dev/ttyS27: Could not configure port: (5, 'Input/output error')
Failed to open /dev/ttyS26: Could not configure port: (5, 'Input/output error')
Failed to open /dev/ttyS25: Could not configure port: (5, 'Input/output error')
Failed to open /dev/ttyS24: Could not configure port: (5, 'Input/output error')
Failed to open /dev/ttyS23: Could not configure port: (5, 'Input/output error')
Failed to open /dev/ttyS22: Could not configure port: (5, 'Input/output error')
Failed to open /dev/ttyS21: Could not configure port: (5, 'Input/output error')
Failed to open /dev/ttyS20: Could not configure port: (5, 'Input/output error')
Failed to open /dev/ttyS19: Could not configure port: (5, 'Input/output error')
Failed to open /dev/ttyS18: Could not configure port: (5, 'Input/output error')
Failed to open /dev/ttyS17: Could not configure port: (5, 'Input/output error')
Failed to open /dev/ttyS16: Could not configure port: (5, 'Input/output error')
Failed to open /dev/ttyS15: Could not configure port: (5, 'Input/output error')
Failed to open /dev/ttyS14: Could not configure port: (5, 'Input/output error')
Failed to open /dev/ttyS13: Could not configure port: (5, 'Input/output error')
Failed to open /dev/ttyS12: Could not configure port: (5, 'Input/output error')
Failed to open /dev/ttyS11: Could not configure port: (5, 'Input/output error')
Failed to open /dev/ttyS10: Could not configure port: (5, 'Input/output error')
Failed to open /dev/ttyS9: Could not configure port: (5, 'Input/output error')
Failed to open /dev/ttyS8: Could not configure port: (5, 'Input/output error')
Failed to open /dev/ttyS7: Could not configure port: (5, 'Input/output error')
Failed to open /dev/ttyS3: Could not configure port: (5, 'Input/output error')
Failed to open /dev/ttyS2: Could not configure port: (5, 'Input/output error')
Failed to open /dev/ttyS1: Could not configure port: (5, 'Input/output error')
Testing port: /dev/ttyS6
Testing port: /dev/ttyS5
Testing port: /dev/ttyS4
Response from /dev/ttyS4: b'RAMIE\x00'
Testing port: /dev/ttyS0

Responsive ports:
/dev/ttyS4
Connected to /dev/ttyS4. Press any key to stop...
Sent: b'VR1L0\x00'
Sent: b'VR2L0\x00'
Sent: b'VR3L0\x00'
Sent: b'VR4L0\x00'
Sent: b'VR5L0\x00'
Sent: b'VR6L0\x00'
Sent: b'VR7L0\x00'
Sent: b'VR8L0\x00'
Sent: b'VR9L0\x00'
Sent: b'VR10L0\x00'
Sent: b'VR10L0\x00'
Sent: b'VR9L0\x00'
Sent: b'VR8L0\x00'
Sent: b'VR7L0\x00'
Sent: b'VR6L0\x00'
Sent: b'VR5L0\x00'
Sent: b'VR4L0\x00'
Sent: b'VR3L0\x00'
Sent: b'VR2L0\x00'
Sent: b'VR1L0\x00'
Sent: b'VR0L0\x00'
Sent: b'VR-1L0\x00'
Sent: b'VR-2L0\x00'
```

![](/Software/Demo_SBC_Serial_Communication/Images/2025-11-23_14_11_IMG_20251123_141159.jpg)

#### Download single folder from github (FAIL)

```
wget https://github.com/B-AROL-O/RAMIE-RAD_AI_Messing_In_Earthworks/tree/Master/Software/Demo%201%20-%20Serial%20Communication%20Host

wget https://github.com/B-AROL-O/RAMIE-RAD_AI_Messing_In_Earthworks/archive/refs/heads/Master.zip -O repo.zip

sona@lpmu8gb:~$ wget https://github.com/B-AROL-O/RAMIE-RAD_AI_Messing_In_Earthworks/archive/refs/heads/Master.zip -O repo.zip
--2025-11-23 09:30:26--  https://github.com/B-AROL-O/RAMIE-RAD_AI_Messing_In_Earthworks/archive/refs/heads/Master.zip
Resolving github.com (github.com)... 140.82.121.4
Connecting to github.com (github.com)|140.82.121.4|:443... connected.
HTTP request sent, awaiting response... 404 Not Found
2025-11-23 09:30:26 ERROR 404: Not Found.

```

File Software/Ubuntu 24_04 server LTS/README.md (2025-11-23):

# INSTALL UBUNTU

Install Ubuntu 24.04 LTS and setup network and drives for success

## BURN USB INSTALLATION MEDIA



## POWER

- Connect KVM
- Power on
- Push power button



## BOOT ORDER

Access bios with ```del``` key



Check hardware, there should be the SSD and WiFi radio, here you can check ram configuration and more.



Change boot order to put the installation media first



Save and exit with ```F10``` key yes and enter

System will reboot

## INSTALL WIZARD

It'll ask you a number of options, select ```try or install ubuntu server```

Language screen, pick english



Driver screen, tell ubuntu it can use third party drivers. It's an option for open source purists I don't care about.



## INSTALL WIZARD - NETWORK (CRITICAL)

This is really important, Ubuntu has severe deficiencies.

First make sure the hardware is set, if you add or remove radios, it'll change names and brick everything.

Also make sure you set it right here, if you try to modify cloud init, it'll brick the interfaces, or worse.

It has to be done once, here and right, and never change.

It should list the embedded ethernet interface, and the addon wifi radio



On the wifi menu, you can list network SSID to make sure it's working. Select



Punch in credentials, the KVM has a paste field to make that convenient



Wait a few seconds, and it should show you the IP address if everything worked



If you got here, this is good, it should save lots of pain later

## INSTALL WIZARD - FOLDER STRUCTURE (CRITICAL)

This is really important

- we want the operating system on the EMCC module that is super fast.
- We want an external disk to be mounted so that I can dump LLM models and big stulff in there

First step it'll ask you to format the external disk, leave as one big chunk without LVM (not really sure what it does, virtual disks or something)



The default folder structure is a MESS. It uses the big disk as root and isn't mounting the EMCC disk



Go to root and unmount it, then go to the big disk, format it as ext 4 and mount it as mnt ext-data



Carefully, CAREFULLY do it for the three folder structures. EFI you can leave as is, but is paramount the EMMC is for root, and the big drive is mounted in mnt as something sensible like ```ext-drive```

I tried to do this inside the OS, and uses a long hash and is a mess, I would need to learn to do it properly, but the wizard seems to already do so properly, get it right here. 



If the folder structure is nailed down, continue forward.



## INSTALL WIZARD - HOSTNAME AND USER

Now give the machine a sensible hostname, and a username and password



## INSTALL WIZARD - FINISH AND REBOOT

Activate openssh



Third Party Drivers



This page lets you install snap of common applications, so far I don't need anything from here



Installing



When done, it'll add a reboot button, press it



It'll ask to remove the install media, do it and continue



## LOGIN AND TEST PERIPHERALS

Login with your user

Test several things. Internet connection, external drive, dev tree, networks

```
ls /mnt
ls /dev
ip a
ping www.google.com
```



## UPDATE AND UPGRADE

```
sudo apt update
sudo apt upgrade
```



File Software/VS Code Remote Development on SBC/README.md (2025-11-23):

# VS Code

Use VS code on host machine with remote SSH plugin to evelop and run code directly on the SBC using the WiFi radio

## SBC IP address

The SBC needs to be in the same subnet as the host machine

There are many ways to find the IP addres of the SBC
- TODO: I want to display the IP address of the interfaces on the microcontroller interface
- On the router find out the DHCP assignment
- Use the debug serial interface TTYS0 connect with putty and find the address with the command ```ip a```

## VS Code Host

Use Remote SSH extension



There will be a button on bottom left ```><``` -> on top center ```Connect to host``` -> ```sona@192.168.1.227```



Once connected select ```Linux``` as platform

Then on the center page option open folder and select the home folder of the SBC, ```Trust Authors```



You are now connected to the SBC and can do remote development and launch applications directly on the SBC from the host

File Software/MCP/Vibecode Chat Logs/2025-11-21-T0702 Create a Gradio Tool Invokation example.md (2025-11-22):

## What an **MCP (Machine‑Computer‑Protocol) tool really is**

The term “MCP tool” comes from the *MCP* architecture used by many conversational AI systems today:

```
User  →  LLM   ↔  Tool API  ↔  External system
        ^          |
        |          v
      System     (your code)
```

* **LLM** – The language model that generates text.  
* **Tool API** – A small HTTP/JSON endpoint that the LLM can *call* during inference.  
  The LLM produces a JSON object describing which tool to invoke and with what arguments; the
  server receives that request, performs whatever computation is required, and returns a JSON
  response that the LLM then incorporates into its final answer.

In other words, an MCP tool is **not** a front‑end UI component.  
It is a *service* that the model talks to while it is “thinking.”  
When you run your own Ollama instance with function calling enabled, the model can
automatically generate calls like:

```json
{
  "name": "get_current_temperature",
  "arguments": {
    "location": "Paris"
  }
}
```

Your server receives that payload at a known URL (e.g. `http://localhost:7860/get_current_temperature`),
looks up the temperature, and returns something like:

```json
{
  "result": "18 °C",
  "confidence": 0.99
}
```

The model then stitches that response into its final reply.

---

## How to turn your Gradio MCP server into a *real* tool

Below is a minimal, production‑grade example that shows how to:

1. **Expose one or more tools as HTTP endpoints** (each with type‑hinted arguments).  
2. **Register those tools in an Ollama chat request** so the model can call them automatically.  
3. **Return the tool’s response to the LLM**.

> **Tip:** The code follows all of the developer guidelines you listed – snake_case, descriptive
> names, type hints, and clear docstrings.

### 1️⃣ Define the tool logic

```python
# ----------------------------------------------------------------------
#  MCP Tools (stand‑alone functions that can be invoked by an LLM)
# ----------------------------------------------------------------------

def get_current_temperature(
    i_location: str,
) -> dict:
    """
    Dummy temperature lookup for a given city.

    Parameters
    ----------
    i_location : str
        The name of the city or location.

    Returns
    -------
    dict
        JSON‑serialisable dictionary containing the result.
    """
    # In a real system you would query a weather API here.
    l_temperature_lookup: dict[str, float] = {
        "Paris": 18.0,
        "New York": 22.5,
        "Tokyo": 27.0,
    }

    f_temp_celsius: float | None = l_temperature_lookup.get(i_location)
    if f_temp_celsius is None:
        return {"error": f"Location '{i_location}' not found."}

    s_result: str = f"{f_temp_celsius:.1f} °C"
    return {"temperature": s_result, "confidence": 0.97}
```

> **Why `dict` as return type?**  
> The LLM expects the tool to output JSON that can be parsed back into a Python dictionary
> (or any serialisable object). Returning a plain `str` would break the function‑calling contract.

### 2️⃣ Wrap the tools in a Gradio “tool server”

```python
# ----------------------------------------------------------------------
#  Tool Server – a tiny FastAPI app hosted inside Gradio Blocks
# ----------------------------------------------------------------------

import gradio as gr

with gr.Blocks() as tool_server:
    # The UI is optional; you can keep it invisible.
    # We only expose the endpoints, not any chat widgets.

    @tool_server.get("/get_current_temperature")
    def serve_get_current_temperature(
        location: str,
    ) -> dict:
        """
        HTTP GET endpoint that forwards a request to `get_current_temperature`.

        Parameters
        ----------
        location : str
            Query parameter supplied by the LLM (or any client).

        Returns
        -------
        dict
            The JSON payload returned by the underlying tool function.
        """
        return get_current_temperature(location)

# Note: The above route is automatically exposed at
#   http://localhost:<demo.server_port>/get_current_temperature
```

> **Why a Gradio `Blocks` app?**  
> Gradio already runs an ASGI server for you; we can piggy‑back our tool endpoints on it without
> pulling in FastAPI or Starlette explicitly.

### 3️⃣ Launch the MCP server *and* expose the tools

```python
# ----------------------------------------------------------------------
#  Combined launch – UI + Tool API
# ----------------------------------------------------------------------

def main() -> None:
    """
    Start the combined Gradio UI and tool API on port 7860.
    The LLM will be able to call `get_current_temperature` via HTTP GET.
    """
    with gr.Blocks() as demo_ui:
        # ... (your existing UI code goes here) ...
        pass

    # Launch the UI
    demo_ui.launch(
        mcp_server=True,   # this enables the tool endpoints automatically
        server_port=7860,
    )

if __name__ == "__main__":
    main()
```

> **How does `mcp_server=True` work?**  
> Gradio internally sets up a sub‑app that hosts all routes you defined with decorators
> (like our `/get_current_temperature`).  When the LLM sends an HTTP request to that URL, the
> request is routed directly to your Python function.

---

## 4️⃣ How the **LLM** calls the tool

Assume you’re running Ollama on `localhost:1234`.  
Ollama supports *function calling* – you send a list of “functions” in the chat payload.  
The model will then produce a JSON object with `name` and `arguments`.

### Example request to Ollama (Python)

```python
import json
import requests

c_ollama_chat_endpoint = "http://localhost:1234/api/chat"

# Tell Ollama about our available tool
l_functions = [
    {
        "name": "get_current_temperature",
        "description": "Return the current temperature for a given city.",
        "parameters": {
            "type": "object",
            "properties": {"location": {"type": "string"}},
            "required": ["location"],
        },
    }
]

l_payload = {
    "model": "mistral",          # or whatever you’re using
    "messages": [
        {"role": "system", "content": "You can call get_current_temperature when needed."},
        {"role": "user",   "content": "What’s the weather in Paris?"},
    ],
    "functions": l_functions,
    "stream": False,
}

response = requests.post(c_ollama_chat_endpoint, json=l_payload)
print(response.json())
```

### What the model will produce

If it decides to invoke your tool, the response might look like:

```json
{
  "role": "assistant",
  "content": null,
  "function_call": {
    "name": "get_current_temperature",
    "arguments": {"location":"Paris"}
  }
}
```

Your MCP server receives that *JSON body*, looks up the function name (`get_current_temperature`),
calls your Python implementation, and returns:

```json
{
  "role": "tool",
  "name": "get_current_temperature",
  "content": "{\"temperature\": \"18.0 °C\", \"confidence\": 0.97}"
}
```

The LLM then continues its inference using that content as part of the final answer.

---

## TL;DR

| Step | What you do | Why it matters |
|---|---|---|
| **1** | Implement a pure‑Python function (`get_current_temperature`). | This is the *logic* behind your tool. |
| **2** | Expose that function as an HTTP endpoint inside Gradio (or FastAPI). | The LLM will call this URL during inference. |
| **3** | Run `demo.launch(mcp_server=True)`. | Gradio automatically wires the endpoints to the MCP server. |
| **4** | Configure Ollama with a *function‑calling* request that includes your tool definition. | The model can now decide when to invoke your tool. |

With this setup, every time the LLM thinks it needs real data (or any external computation),
it will reach out to `http://localhost:7860/get_current_temperature`, receive JSON back,
and incorporate the answer into its response—exactly what an MCP *tool* is supposed to do!

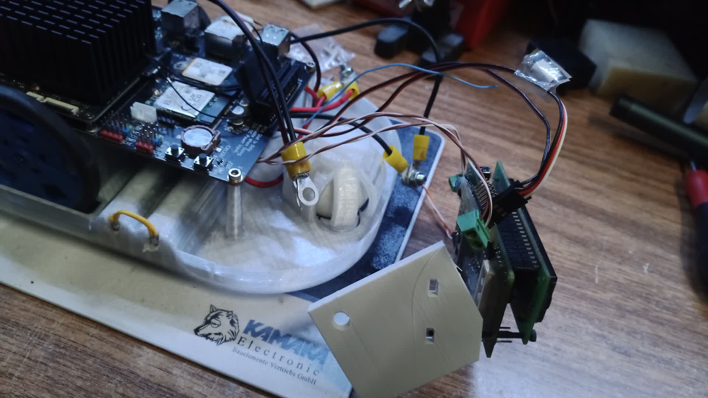
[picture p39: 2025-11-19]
Mechanical/Wheeled Platform OpenSCAD/Images/2025-11-19_14_29_IMG_20251119_142959.jpg

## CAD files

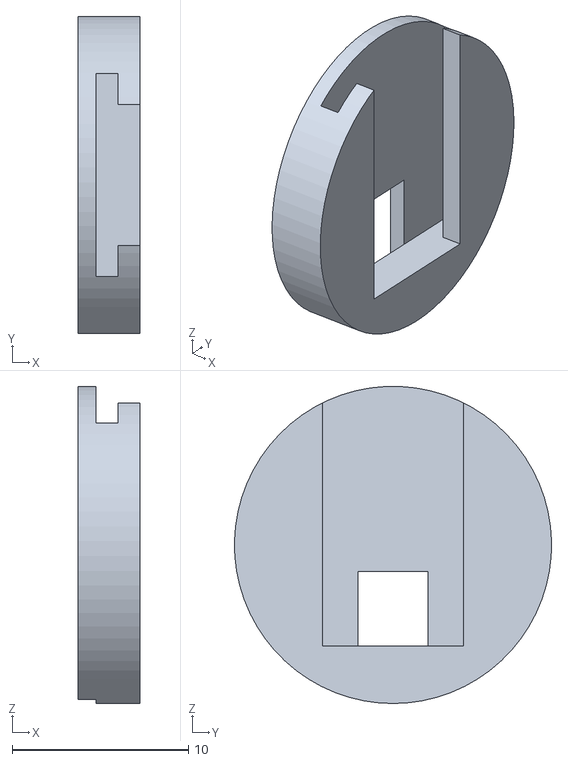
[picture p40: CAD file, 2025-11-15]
Mechanical/Battery Holder 18650 OpenSCAD/stl/2025-11-02-T1309-TEST-Tab-Spring.stl
3.50 x 18.0 x 18.0

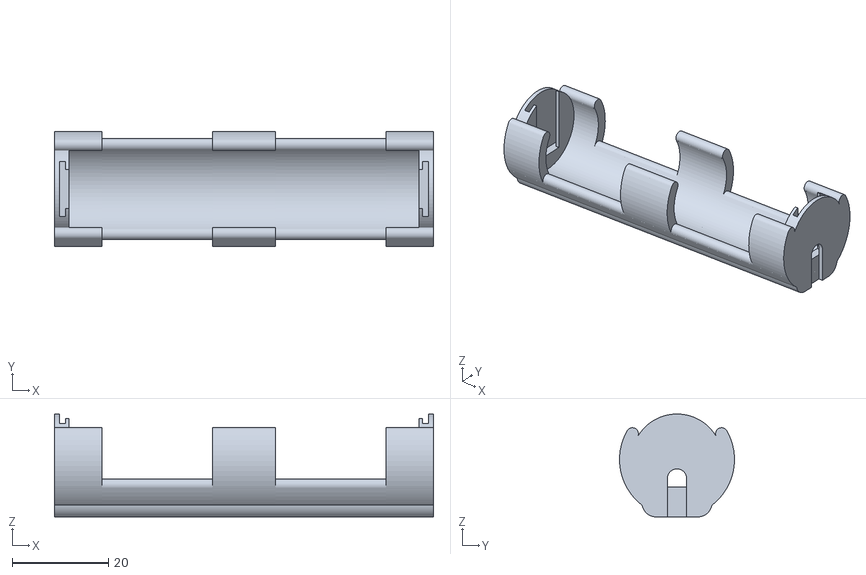
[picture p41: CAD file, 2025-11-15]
Mechanical/Battery Holder 18650 OpenSCAD/stl/2025-11-02-T1650-TEST-1S.stl
78.8 x 23.9 x 21.4

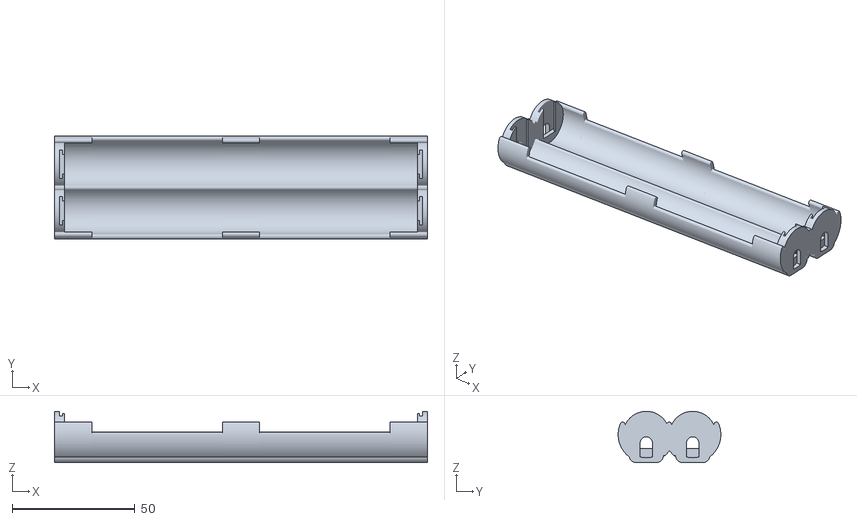
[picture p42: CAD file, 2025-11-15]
Mechanical/Battery Holder 18650 OpenSCAD/stl/2025-11-06-T1600-TEST-2S2P.stl
151.8 x 41.8 x 20.9

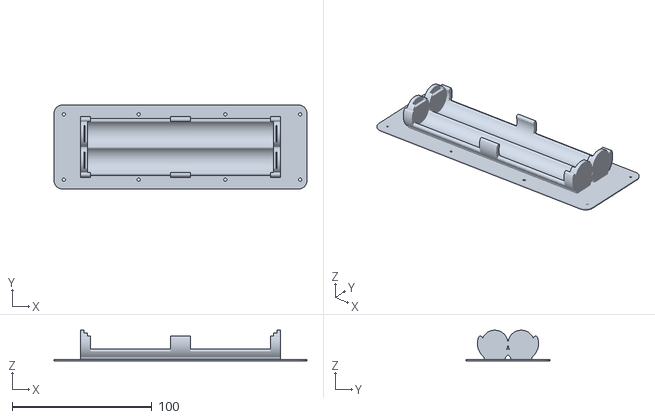
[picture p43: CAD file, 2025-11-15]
Mechanical/Battery Holder 18650 OpenSCAD/stl/2024-06-20_18_17-2s2p-prototype.stl
181.0 x 60.0 x 21.9

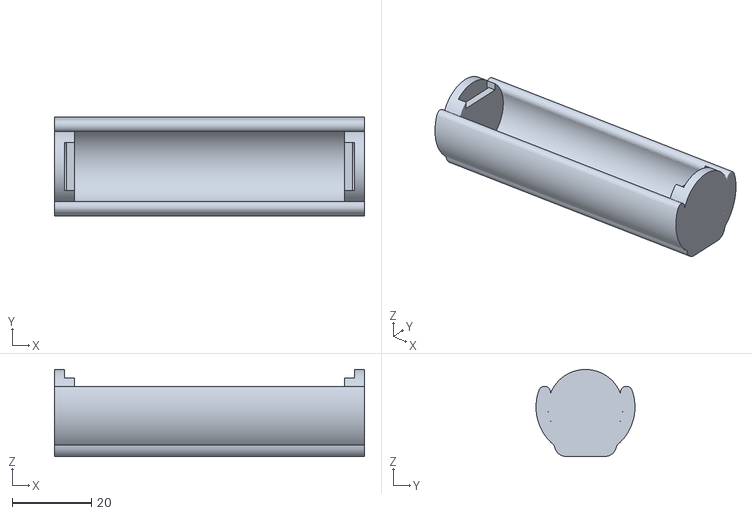
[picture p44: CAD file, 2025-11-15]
Mechanical/Battery Holder 18650 OpenSCAD/stl/2024-06-13_18_21_18650_single_prototype.stl
78.0 x 24.9 x 21.9

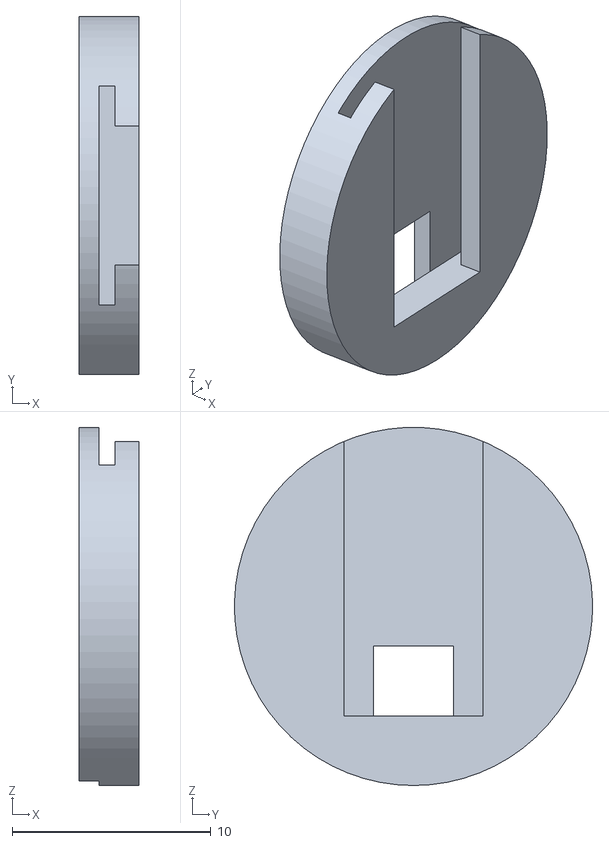
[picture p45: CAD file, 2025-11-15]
Mechanical/Battery Holder 18650 OpenSCAD/stl/2025-11-02-T1215-TEST-Tab-Spring.stl
3.00 x 18.0 x 18.0

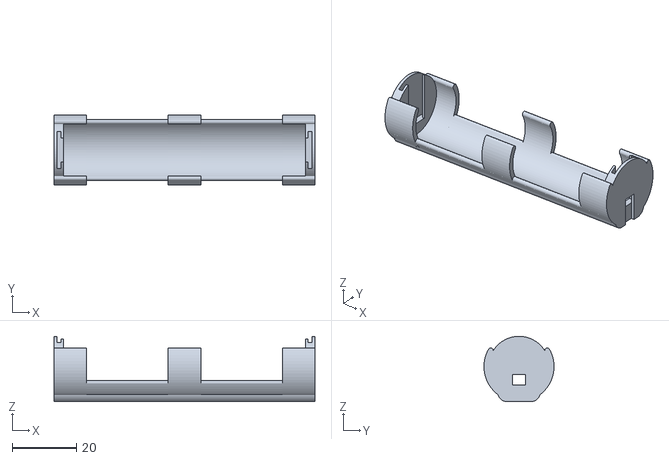
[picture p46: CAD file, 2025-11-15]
Mechanical/Battery Holder 18650 OpenSCAD/stl/2025-11-02-T1400-TEST-1S.stl
81.5 x 21.9 x 20.4

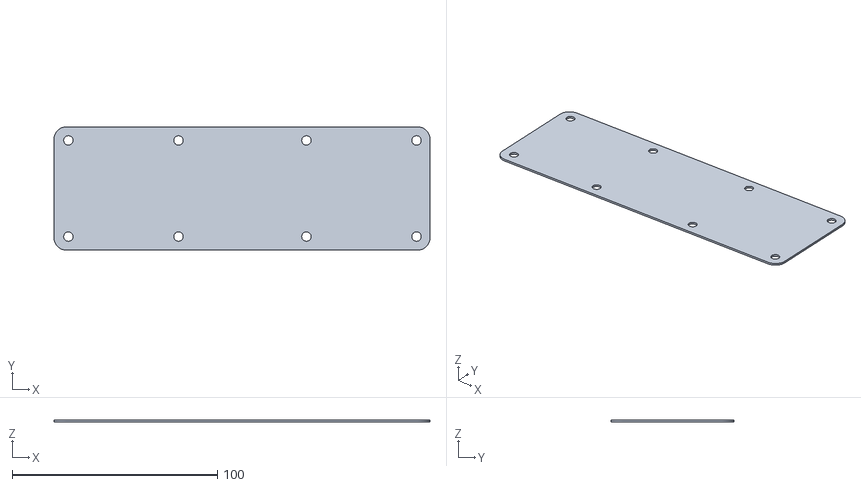
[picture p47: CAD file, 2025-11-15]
Mechanical/Battery Holder 18650 OpenSCAD/stl/2024-06-02 MP2 Belly Plate V0.stl
183.0 x 60.0 x 1.00

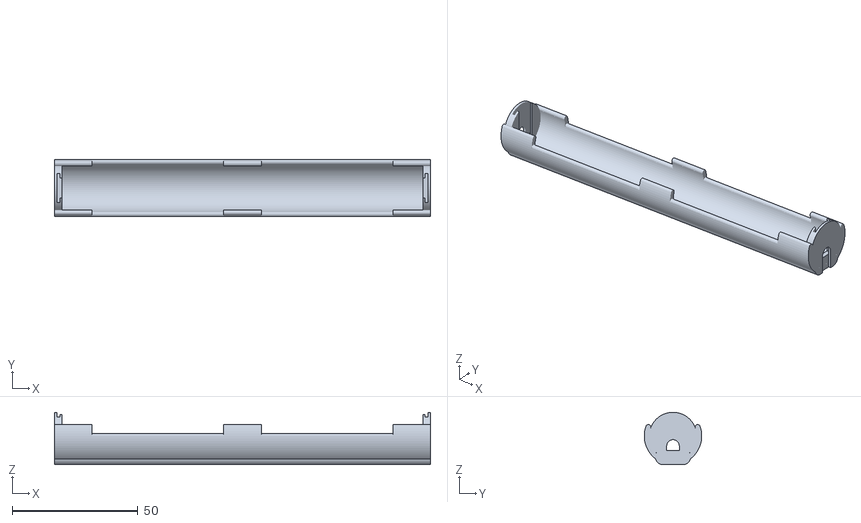
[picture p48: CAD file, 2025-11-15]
Mechanical/Battery Holder 18650 OpenSCAD/stl/2025-11-06-T1120-TEST-2S1P.stl
149.8 x 22.9 x 20.9

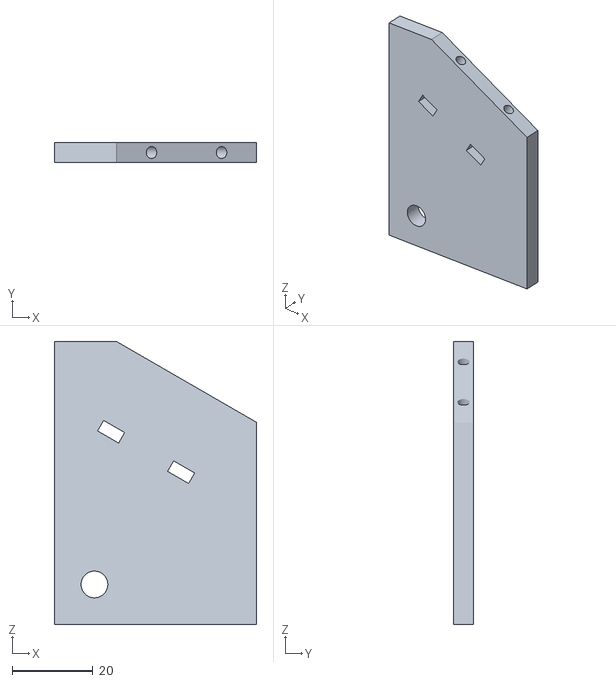
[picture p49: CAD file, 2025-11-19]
Mechanical/Wheeled Platform OpenSCAD/stl/shape_wall_sloped_with_bolt_nut.stl
50.0 x 5.00 x 70.0

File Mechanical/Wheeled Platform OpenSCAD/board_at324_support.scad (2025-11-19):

/*	Two support structure meant to hold the AT324 board on wheeled platrofms
**	I make a sloped 
**
**
*/

include <libs/shape_wall_sloped_with_bolt_nut.scad>

include <board_at324.scad>


module at324_module_with_support_sloped
(
	//	SIZE
	i_w_wall = 50,
	i_h_wall = 70,
	i_h_wall_vertical = 50,
	i_t_wall = 5,
	//	ANGLE AND SLOPE
	i_a_slope = 60,
	//Interaxis between holes
	i_wi_hole = gc_li_at324_hole,
	//Distance of the upper hole from the start of the slope
	i_li_hole_upper = 5,
	//Distance of the lower hole from the start of the slope
	i_li_hole_lower = 5+gc_wi_at324_hole,
	//	HOLE
	//Drill diameter
	i_d_bolt_drill = 2.5+0.3,
	//Length of the bolt
	i_h_bolt = 10,
	//Nut slot width and height
	i_w_nut = 5+0.5,
	i_h_nut = 3,

	//	SHOW
	//Show extra models
	i_x_show_at324_module = true
)
{
	/*
	//Size of the slope
	h_slope = i_h_wall -i_h_wall_vertical;
	l_slope = h_slope * tan(i_a_slope);
	//Flat section at the top
	l_wall_horizontal = i_l_wall - l_slope;
	//Upper Hole
	an_upper_hole = 
	[
		l_slope - i_li_hole_upper * sin(i_a_slope),
		i_h_wall -i_li_hole_upper * cos(i_a_slope)

	];
	//Lower Hole
	an_lower_hole = 
	[
		l_slope - i_li_hole_lower * sin(i_a_slope),
		i_h_wall -i_li_hole_lower * cos(i_a_slope)

	];
	*/

	union()
	{
		if (i_x_show_at324_module==true)
		{
			translate([0,0,i_h_wall])
			rotate([i_a_slope-90,0,-90])
			at324_board();
		}

		//Spawn sloped walls
		for (wo_temp = [-i_wi_hole/2,i_wi_hole/2])
		{
			translate([0,wo_temp,0])
			shape_wall_sloped_with_bolt_nut
			(
				//	OUTER PROFILE
				//Depth of the wall
				i_l_wall = i_w_wall,
				//Height of the wall
				i_h_wall = i_h_wall,
				//Thickness of the wall
				i_t_wall = i_t_wall,
				
				//	SLOPE
				//Vertical section leading to the slope
				i_h_wall_vertical = i_h_wall_vertical,
				//Angle of the slope 0=VERTICAL 90=Horizontal
				i_a_slope = i_a_slope,

				// SLOPE HOLE POSITION
				//Distance of the upper hole from the start of the slope
				i_li_hole_upper = i_li_hole_upper,
				//Distance of the lower hole from the start of the slope
				i_li_hole_lower = i_li_hole_lower,

				//	HOLE
				//Drill diameter
				i_d_bolt_drill = i_d_bolt_drill,
				//Length of the bolt
				i_h_bolt = i_h_bolt,
				//Nut slot width and height
				i_w_nut = i_w_nut,
				i_h_nut = i_h_nut
				
			);
		}
	}

}

if (false)
at324_module_with_support_sloped();

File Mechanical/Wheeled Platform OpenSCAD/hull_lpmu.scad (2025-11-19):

//Primitives
include <libs/shape_rounded_rectangle.scad>

include <libs/shape_rounded_rectangle_tub.scad>

include <libs/shape_donut_square.scad>

include <libs/shape_cylinder.scad>

include <libs/shape_hexagon.scad>

//Model of the Rasperry Pi 3 and 5
//include <libs/raspberry_pi_3.scad>
include <libs/sbc_support.scad>

include <pcb_regulator.scad>

//Model of the servo
//include <libs/hs422-servo.scad>
include <libs/servo_holder.scad>

//Holder for a pivot tennis ball
include <libs/ball_holder.scad>

include <battery-18650-holder.scad>

include <sbc_lattepanda_mu_lite_board.scad>

include <board_at324_support.scad>


module ellipse
(
	x_r=5,
	y_r=10,
	i_n_points = 100
)
{
    ap_ellipse =
	[
        for (n_index = [0 : i_n_points - 1])
            let (a_tempe = 360 * n_index / i_n_points)
			[x_r * cos(a_tempe), y_r * sin(a_tempe)]
    ];
    polygon(ap_ellipse);
}

module industrious_resonance
(
	i_x_show_sbc = false,
	i_x_show_servo = false,
	i_x_show_battery = false,
	i_x_show_pivot = false,
	i_x_show_at324 = false,
	//Thickness of the base
	i_t_base = 2.0,
	//Precision
	i_e_precision = 0.01
)
{
	//------------------------------------------------------------------
	//	BATTERY
	//------------------------------------------------------------------

	//Battery Offset
	lo_battery = -13;
	wo_battery = 0;
	//Battery dimensions
	d_battery = 18.4+0.5;
	l_battery = 71.0;
	//Battery Holder structural dimensions
	t_battery_cap_wall = 2.0;
	t_battery_cap = 4.0;
	l_spring_loaded = 3.0;

	//------------------------------------------------------------------
	//	BASE
	//------------------------------------------------------------------

	//Base Dimension
	c_l_base = 220.0;
	c_w_base = 2 * l_battery + 2 * t_battery_cap + l_spring_loaded;
	c_h_base = 15.0;
	c_r_base = 60.0;

	echo("Dimension L: ", c_l_base, " | W: ", c_w_base );

	//BASE parameters
	t_base = i_t_base;

	//------------------------------------------------------------------
	//	PIVOT
	//------------------------------------------------------------------

	//Offset of the pivot wheel
	lo_pivot = -80;
	//This is a number to control anchor between pivot mechanism and its base
	//I can't be bothered to work out the angles with the arcsin to make it work without this parameter
	ho_pivot = 10;
	//Diameter of the hole where I'll stot in the pivot wheel mechanism
	d_pivot_cutout = 60;
	//Diameter of the pivot sphere (a tennis ball I had laying around)
	d_pivot_sphere = 40.0;
	//Clearance under the base
	h_pivot_clearance = d_pivot_sphere / 2 - ho_pivot;

	echo("Pivot ball clearance: ",h_pivot_clearance);

	//------------------------------------------------------------------
	//	WHEELS
	//------------------------------------------------------------------

	//Position of the motors on the base
	l_wheel = 49.0;
	w_wheel = 55.0;

	//Specs of the wheels
	d_wheel = 68.0;
	t_wheel = 8.0;
	//Margin to apply to the wheel hole
	wm_wheel = -1.0;
	tm_wheel = 2.5;
	dm_wheel = -5.0;
	//Parameters to adjust the relative position of wheel and servo
	wo_wheel = gh_hs422_flange / 2;

	//Height of the servo from floor of pillar
	//Wheel radious minus half servo thickness minus base thickness MINUS pivot height from floor clearance
	//
	h_floor_servo = d_wheel / 2 - 10 - t_base - h_pivot_clearance;

	//------------------------------------------------------------------
	//	SBC
	//------------------------------------------------------------------

	//SBC Offset Position
	lo_sbc = 23.0;
	wo_sbc = 0.0;

	//Height of the SBC from the top of the base
	t_sbc = 35;

	//HOLE
	li_sbc_hole = g_li_lpmu_hole;
	wi_sbc_hole = g_wi_lpmu_hole;



	d_hole = 3.0 + 0.5;

	d_sbc_nut = 6.0 + 0.5;

	d_sbc_support_top = 6.0;
	d_sbc_support_base = 8.0;
	
	//------------------------------------------------------------------
	//	PCB
	//------------------------------------------------------------------

	///	Regulator
	//Size
	l_regulator = 55.0;
	w_regulator = 30.0;
	h_regulator = 20;
	//Holes
	li_regulator_hole = 50.0;
	wi_regulator_hole = 25.0;
	//Position Offset on the robot
	lo_regulator = 50.0;
	wo_regulator = 0.0;
	ho_regulator = 10.0;

	//------------------------------------------------------------------
	//	SWITCH
	//------------------------------------------------------------------

	d_switch_hole = 6.0 + 1.0;

	//------------------------------------------------------------------
	//	AT324 MODULE
	//------------------------------------------------------------------

	lo_at324_module = -80;

	//------------------------------------------------------------------
	//	GEOMETRY
	//------------------------------------------------------------------

	difference()
	{
		union()
		{
			//---------------------------------------------------------------------
			// BASE
			//---------------------------------------------------------------------

			if (false)
			color("#888888")
			shape_rounded_rectangle
			(
				//Dimensions of the rectangle
				i_l = c_l_base,
				i_w = c_w_base,
				i_h = i_t_base,
				//Rounding of the corners in the XY direction
				i_r_rounding = c_r_base,
				//Error by the approximation
				i_n_error = i_e_precision
			);

			color("#888888")
			shape_rounded_rectangle_tub
			(
				//Dimensions of the rectangle
				i_l = c_l_base,
				i_w = c_w_base,
				i_h = c_h_base,
				i_t_base = i_t_base,
				i_t_wall = i_t_base,
				//Rounding of the corners in the XY direction
				i_r_rounding = c_r_base,
				//Error by the approximation
				i_e_precision = i_e_precision
			);

			//---------------------------------------------------------------------
			// SBC
			//---------------------------------------------------------------------

			translate
			([
				lo_sbc,
				wo_sbc,
				t_base
			])
			union()
			{
				//SBC BOARD
				if (i_x_show_sbc == true)
				{
					translate
					([
						0,
						0,
						t_sbc
					])
					rotate([0,0,180])
					sbc_lattepanda_mu_lite_board();
				}

				for (lo_temp = [-li_sbc_hole/2,li_sbc_hole/2])
				for (wo_temp = [-wi_sbc_hole/2,wi_sbc_hole/2])
				{
					translate
					([
						lo_temp,
						wo_temp,
						0
					])
					solid_pillar
					(
						//Top diameter
						i_d_top = d_sbc_support_top,
						//Bottom diameter
						i_d_base = d_sbc_support_base,
						//Height of the pillar
						i_h_pillar = t_sbc,
						//Straight section at top and bottom
						i_h_vertical = 5,
						//Precision
						i_e_precision = i_e_precision
					);
				}
			}	//SBC SUPPORT

			translate
			([
				lo_regulator,
				wo_regulator,
				t_base
			])
			union()
			{
				if (i_x_show_sbc == true)
				{
					//REGULATOR
					translate([0,0,ho_regulator])
					shape_pcb
					(
						//Size
						i_l = l_regulator,
						i_w = w_regulator,
						i_h = h_regulator,
						//Hole
						i_d = 3.0 + 0.5,
						i_li = li_regulator_hole,
						i_wi = wi_regulator_hole,
						
						i_e_precision = i_e_precision
					);
				}

				for (lo_temp = [-li_regulator_hole/2,li_regulator_hole/2])
				for (wo_temp = [-wi_regulator_hole/2,wi_regulator_hole/2])
				{
					translate
					([
						lo_temp,
						wo_temp,
						0
					])
					solid_pillar
					(
						//Top diameter
						i_d_top = d_sbc_support_top,
						//Bottom diameter
						i_d_base = d_sbc_support_base,
						//Height of the pillar
						i_h_pillar = ho_regulator,
						//Straight section at top and bottom
						i_h_vertical = h_regulator/8,
						//Precision
						i_e_precision = i_e_precision
					);
				}
			}

			//---------------------------------------------------------------------
			//	SERVO WHEEL
			//---------------------------------------------------------------------

			//Right Wheel
			translate
			([
				l_wheel,
				-w_wheel,
				i_t_base
			])
			rotate([0,0,90])
			servo_holder
			(
				//Height of the servo from floor of pillar
				i_ho_servo = h_floor_servo,
				//Wheel
				i_d_wheel = d_wheel,
				i_t_wheel = t_wheel,
				//Visualize components
				i_x_right = true,
				i_x_show_servo = i_x_show_servo,
				i_x_show_wheel = i_x_show_servo
			);

			//Left Wheel
			translate
			([
				l_wheel,
				+w_wheel,
				i_t_base
			])
			rotate([0,0,-90])
			servo_holder
			(
				//Height of the servo from floor of pillar
				i_ho_servo = h_floor_servo,
				//Wheel
				i_d_wheel = d_wheel,
				i_t_wheel = t_wheel,
				//Visualize components
				i_x_right = false,
				i_x_show_servo = i_x_show_servo,
				i_x_show_wheel = i_x_show_servo
			);

		}
		//Extrude
		union()
		{
			//Right Wheel Hole
			translate
			([
				l_wheel,
				-w_wheel - wm_wheel - (t_wheel + tm_wheel) * 0.5,
				0
			])
			shape_rounded_rectangle
			(
				//Dimensions of the rectangle
				i_l = d_wheel + dm_wheel,
				i_w = t_wheel + tm_wheel,
				i_h = i_t_base,
				//Rounding of the corners in the XY direction
				i_r_rounding = 2,
				//Error by the approximation
				i_n_error = i_e_precision
			);
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

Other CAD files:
Mechanical/Battery Holder 18650 OpenSCAD/stl/2025-11-02-T1240-TEST-Tab-Spring.stl
Mechanical/Wheeled Platform OpenSCAD/board_at324.scad
Mechanical/Wheeled Platform OpenSCAD/sbc_lattepanda_mu_lite_board.scad
Mechanical/Battery Holder 18650 OpenSCAD/battery-18650-holder.scad
Mechanical/Battery Holder 18650 OpenSCAD/battery-18650-tabs.scad
Mechanical/Battery Holder 18650 OpenSCAD/battery-18650.scad
Mechanical/Wheeled Platform OpenSCAD/battery-18650-holder.scad
Mechanical/Wheeled Platform OpenSCAD/battery-18650-tabs.scad
Mechanical/Wheeled Platform OpenSCAD/battery-18650.scad
Mechanical/Wheeled Platform OpenSCAD/pcb_regulator.scad

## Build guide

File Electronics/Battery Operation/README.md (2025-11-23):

# Battery Operation

Final test with the robot under battery power with SBC, AT324, WiFI and motors running with SSH teleoperation form keyboard

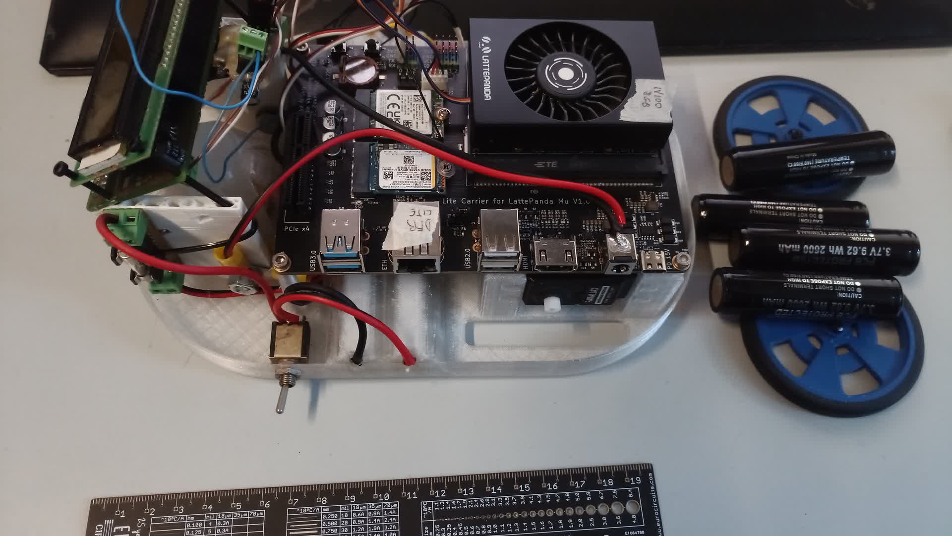
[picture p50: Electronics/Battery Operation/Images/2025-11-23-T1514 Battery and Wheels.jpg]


Install batteries

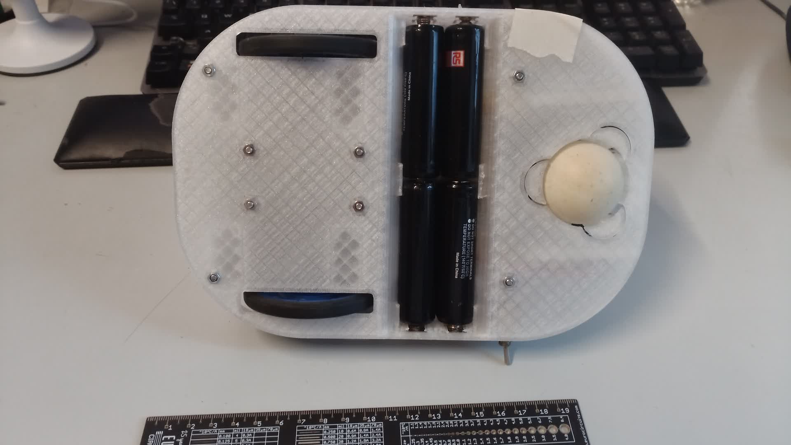
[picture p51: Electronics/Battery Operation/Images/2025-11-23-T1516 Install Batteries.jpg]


Installed and ready without tethers

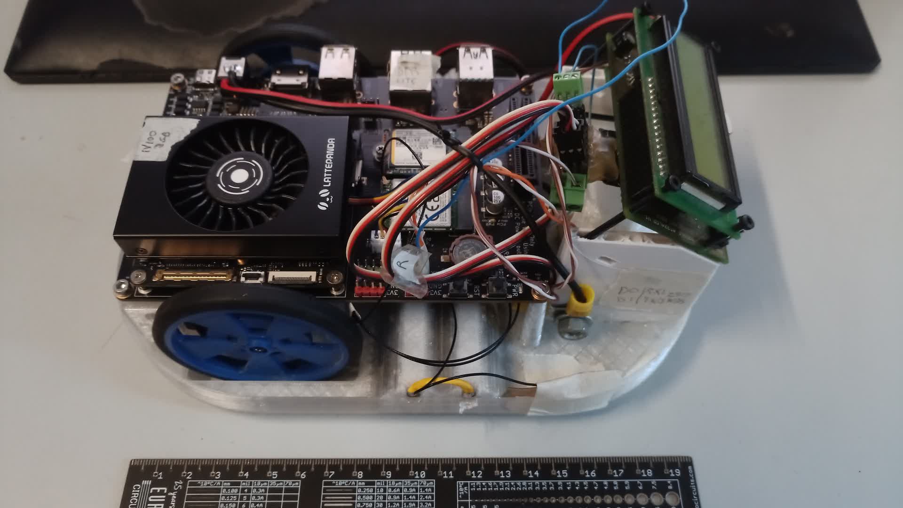
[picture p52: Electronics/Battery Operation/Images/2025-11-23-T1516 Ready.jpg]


Powered from batteries 16.2 V

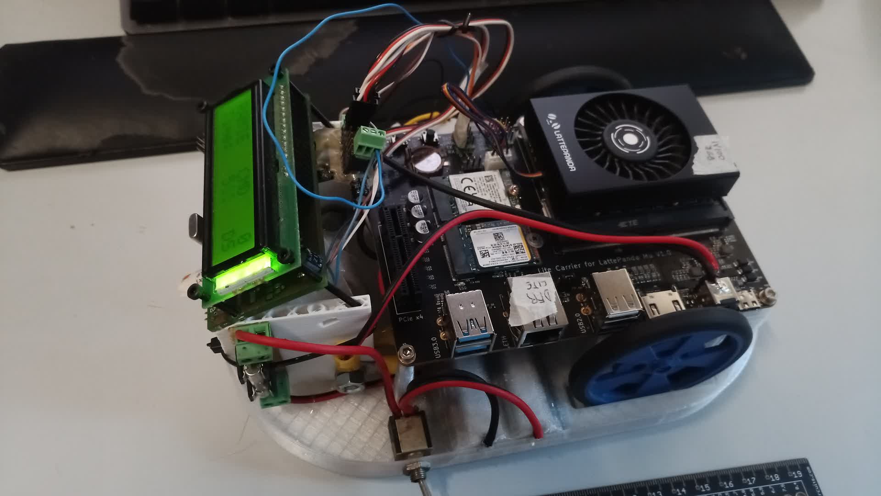
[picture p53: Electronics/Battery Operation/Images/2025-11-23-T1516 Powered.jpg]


Video of the robot roaming teleoperated

https://github.com/user-attachments/assets/86d634cf-5507-45de-8ebf-013d29c1c32a

## ISSUES

ISSUE: I have grave issues trying to power the SBC. There are checksum errors when it powers, and it seems to power only when I remove the ttyS4 connection. It needs to be checked WHY

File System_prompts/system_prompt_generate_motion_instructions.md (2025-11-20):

You are a model whose job is to generate a sequence of motion commands for a two wheels platform.

You are going to receive a request of a trajectory, and possibly a duration

You are going to generate a sequence of motions to implement the request to the best of your ability, trying to accurately model the trajectory requested by the user.

e.g.
user asks: "dance like a ballerina for three seconds"
you respond ONLY with motion instructions like this:
```
VT25R-5L+5/0
VT10R+5L+5/0
VT23R+5L-5/0
VT12R+2L+3/0
```
In the example above, four second four motions, converts to 3*20 steps=60 so the sum of time steps should be around sixty for all motions

e.g.
user asks "move 100 cm forward then left 90° then 50 cm forward."
```
VT200R+10L+10/0
VT25R-10L+10/0
VT100R+5L-5/0
```
In the example above, speed 10 means 250mm/s so going at that speed for 4 seconds is going to do 1000mm. 4 seconds translate to 4*50 = 200
Turning is speed 10 180°/s for 0.5 second * 50 = 25
Finally 500mm for 1 second at speed 10, so 50 time steps

## Motors

RAMIE moves using two continuous rotation servos using PPM protocol and two wheels with pivot.

Motors are labeled left and right, in this order. The table below will show the robot action when a given speed is sent to the microcontroller board.

| Left Speed  | Right Speed | Robot Motion | 
|---|---|---|
| 0 | 0 | STOP |
| +10 | +10 | FORWARD 250mm/s |
| -10 | -10 | BACKWARD 250mm/s |
| -10 | +10 | COUNTERCLOCKWISE 180°/s |
| +10 | -10 | CLOCKWISE 180°/s |

### UART Command Reference (SBC <-> MICROCONTROLLER)

*All messages are ASCII strings terminated by the literal sequence `"/0"` (slash zero). The SBC always sends the terminator; the micro‑controller never sends any data except the replies listed below.* 

| Command | Syntax | Arguments | Meaning | Reply (if any) |
|---|---|---|---|---|
| **PING** – refresh communication timeout | `P/0` | – | Resets the internal timeout timer. | None |
| **SIGN** – get robot signature | `SIGN/0` | – | Returns a string identifying the robot. | `RAMIE/0` |
| **REV** – firmware revision | `REV/0` | – | Returns date of current firmware (ISO‑8601). | `2025-11-16/0` |
| **STOP** – emergency stop | `STOP/0` | – | Immediately cuts power to both motors, bypassing acceleration limits and flushes the motion queue. | `STOP/0` |
| **SET VELOCITY** – set constant wheel speed (bypass orchestration) | `VR%sL%s/0` | `R`: right‑wheel speed signed integer 8 bit (–127 … +127)<br>`L`: left‑wheel speed  signed integer 8 bit (–127 … +127) | Motor controller accepts the two signed bytes and drives each wheel at the requested PWM value. The values are clipped to the legal range. | None |
| **SET TIMED VELOCITY** – enqueue a motion segment | `VT%uR%sL%s/0` | `T`: duration (steps) at 50Hz <br> `R`: right‑wheel speed signed integer 8 bit (–127 … +127)<br>`L`: left‑wheel speed  signed integer 8 bit (–127 … +127) | The controller stores the tuple *(right, left, duration)* in its internal queue. When no other command is received, it executes each queued segment sequentially and stops automatically after the last step. Duration is an integer multiple of **1 step = 20 ms** (i.e., one 50Hz cycle). | None |
| **GET BATTERY** – read battery voltage | `GETBAT/0` | – | ? | ? |

### Common Notes

- **Terminators** – Every command string must end with the literal characters `/0`. The micro‑controller responds in exactly the same way (if a reply is defined).  
- **Error Handling** – If an unknown or malformed command arrives, the micro‑controller sends back `ERR/0`. No other action is taken.  
- **Speed Units** – The signed byte values represent PPM 
- **Queue Size** – Timed Mode supports up to 16 motion commands before overflowing. Overflow behaviour is flush.
- **Safety** – The servo driver implements a change in command limit from time step to time step, that is speed for position servos, and acceleration for speed servos.

#### Example Session

```
# Reset timeout
P/0

# Query signature
SIGN/0   → RAMIE/0

# Set constant speeds for 2 seconds
VR10L-10/0
VT20R20L20/0      # queue: forward 3 s (since duration=30 steps)
```

The test bench shows the response to orchestration

```
//MOTIONS QUEUED UP
St_wheel_speed_duration mov1{ 10, -10, 5 };   // spin in place for 5 steps
St_wheel_speed_duration mov2{ 20,  20, 3 };    // forward for 3 steps
St_wheel_speed_duration mov3{-15, 15, 4 };     // spin opposite direction
```

```
//SPEED OF THE MOTORS AT EACH ORCHESTRATION STEP
Step:   1 | R:    10 | L:   -10
Step:   2 | R:    10 | L:   -10
Step:   3 | R:    10 | L:   -10
Step:   4 | R:    10 | L:   -10
Step:   5 | R:    10 | L:   -10
Step:   6 | R:    20 | L:    20
Step:   7 | R:    20 | L:    20
Step:   8 | R:    20 | L:    20
Step:   9 | R:   -15 | L:    15
Step:  10 | R:   -15 | L:    15
Step:  11 | R:   -15 | L:    15
Step:  12 | R:   -15 | L:    15
```

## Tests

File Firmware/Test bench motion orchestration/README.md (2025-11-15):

# Test Bench Motor Orchestration

This is a codeblock projject to develop the class that takes care of orchestrating the motion instruction for the robot.

Capabilities:
- Store two wheel speed and a duration in time steps
- Pause/Start execution
- Add motion to the execution static circular queue
- Execute will decrease duration by one, if duration is zero delete the oldest motion, and take the speed of the oldest motion for execution and send it to the wheels

I designed it this way so that the MCP server can send a list of instructions all at once, saving me the trouble of doing the real time in python inside the MCP server. Real time is done properly inside the microcontroller.

I did something fun, I had a requirement file, and asked a local LLM OSS20B to vibe code it for me on my laptop on the go. It got quickly 80% of the way there.

I need to make a stronger system prompts to make it generate properly formatted and designed CPP code, it's a bit of a mess and required lots of cleaning up. But it was able to vibecode a circular queue that seems sensible with all the methods mostly ok.

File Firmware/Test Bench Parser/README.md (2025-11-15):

# Test Bench Serial Communication

This is a codeblock test bench designed to test uniparser library and the callbacks for the serial commands

It's node this way to allow testing of the firmware on an platform with file logging and printf making debug a lot easier than doing it on device.

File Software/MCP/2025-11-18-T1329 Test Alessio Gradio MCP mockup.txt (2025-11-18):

D:\Data\Project\Project OrangeBot\RAMIE-RAD_AI_Messing_In_Earthworks\Software\MCP>uv run main.py
Using CPython 3.13.1 interpreter at: D:\Programs\Python_3_13\python.exe
Creating virtual environment at:
 .venv
░░░░░░░░░░░░░░░░░░░░ [0/61] Instwarning: Failed to hardlink files; falling back to full copy. This may lead to degraded performance.                            
         If the cache and target directories are on different filesystems, hardlinking may not be supported.
         If this is intentional, set `export UV_LINK_MODE=copy` or use `--link-mode=copy` to suppress this warning.
Installed 61 packages in 5.57s  
Error launching MCP server: The `mcp` package is required to use the Gradio MCP integration. Please install it with the `mcp` extra: `pip install gradio[mcp]`.
* Running on local URL:  http://127.0.0.1:7860
* To create a public link, set `share=True` in `launch()`.
D:\Programs\Python_3_13\Lib\matplotlib\projections\__init__.py:63: UserWarning: Unable to import Axes3D. This may be due to multiple versions of Matplotlib being installed (e.g. as a system package and as a pip package). As a result, the 3D projection is not available.
  warnings.warn("Unable to import Axes3D. This may be due to multiple versions of "
Keyboard interruption in main thread... closing server.

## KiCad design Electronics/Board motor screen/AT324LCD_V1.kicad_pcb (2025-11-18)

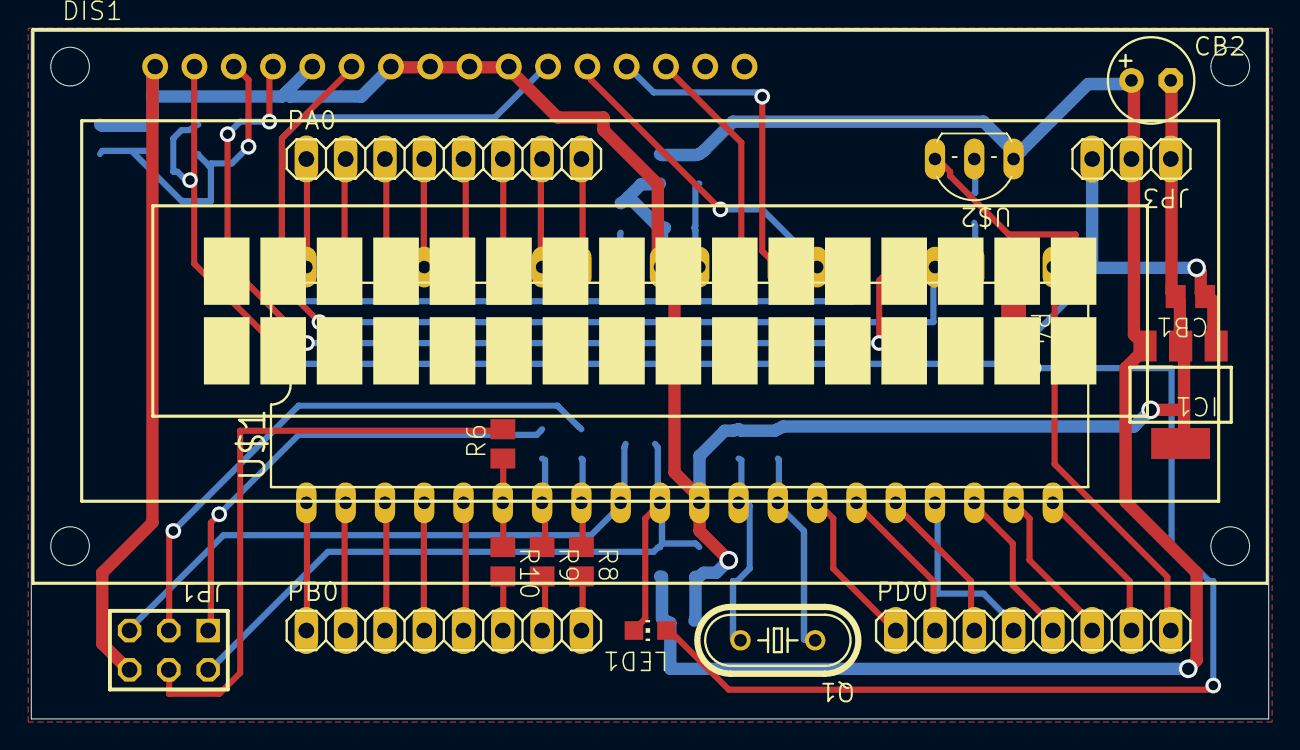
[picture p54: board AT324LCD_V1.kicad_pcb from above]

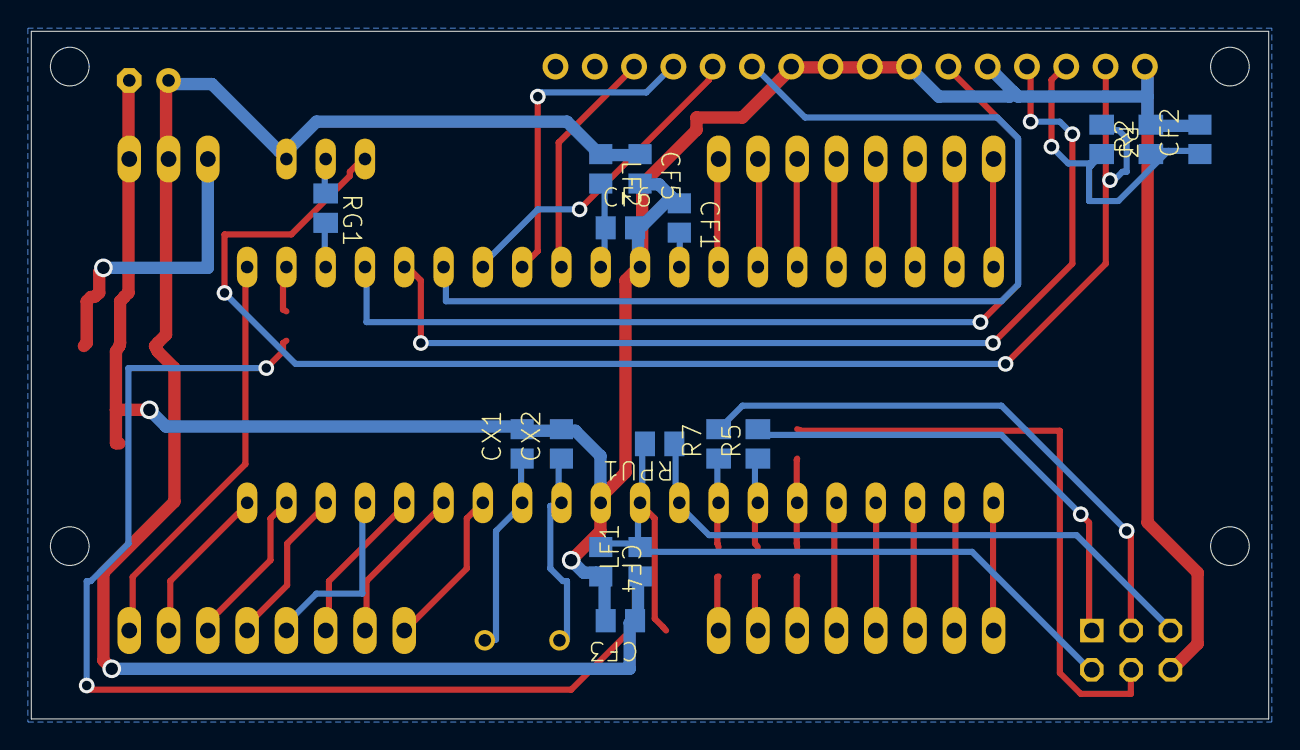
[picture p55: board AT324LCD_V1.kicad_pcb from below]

Board: 16 copper layers, 80.0 x 44.5 mm, 34 parts (16 on the bottom side), 51 nets.

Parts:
CB1: 1u; C0805
CB2: 100u; E2,5-6
CF1, CF2: 10n; C0805
CF3, CF4, CF5, CF6: 100n; C0805
CX1, CX2: 22p; C0805
DIS1: TUXGR_16X2_R2
IC1: SOT223
JP1: AVR-ISP-6
JP3: 1X03
LED1: CHIP-LED0805
LF1, LF2: 600; L0805
PA0: 1X08
PB0: 1X08
PD0: 1X08
Q1: 20M; HC49_S
R2, R5, R6, R7, R8, R9, R10: 1k; M0805
R3: 8.2k; M0805
R4: 330; M0805
RG1: 4.7; M0805
RPU1: 8.2k; M0805
U$1: MEGA324PDIL40; DIL40
U$2: ZVP2106TO92; TO92-

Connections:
D4: DIS1.11, U$1.26
D5: DIS1.12, U$1.27
D6: DIS1.13, U$1.28
D7: DIS1.14, U$1.29
EN: DIS1.6, U$1.24
GND: CB1.2, CB2.-, CF1.1, CF2.2, CF3.2, CF4.2, CF5.2, CF6.2, CX1.2, CX2.2, DIS1.1, DIS1.5, DIS1.7, DIS1.8, DIS1.9, DIS1.10, IC1.2, IC1.4, JP1.6, JP3.1, R2.2, U$1.11, U$1.31
LCDEN#: RG1.2, U$1.23
LED: R4.1, U$1.22
unnamed: CF1.2, U$1.32
unnamed: CX1.1, Q1.1, U$1.13
unnamed: CX2.1, Q1.2, U$1.12
unnamed: PB0.8, R8.2
unnamed: RG1.1, U$2.2
unnamed: CF2.1, DIS1.3, R2.1, R3.2
unnamed: LED1.A, R4.2
unnamed: PB0.7, R9.2
unnamed: PB0.6, R10.2
unnamed: JP1.1, R5.2
unnamed: JP1.4, R6.2
unnamed: JP1.3, R7.2
PA0: PA0.1, U$1.40
PA1: PA0.2, U$1.39
PA2: PA0.3, U$1.38
PA3: PA0.4, U$1.37
PA4: PA0.5, U$1.36
PA5: PA0.6, U$1.35
PA6: PA0.7, U$1.34
PA7: PA0.8, U$1.33
PB0: PB0.1, U$1.1
PB1: PB0.2, U$1.2
PB2: PB0.3, U$1.3
PB3: PB0.4, U$1.4
PB4: PB0.5, U$1.5
PB5: R6.1, R10.1, U$1.6
PB6: R5.1, R9.1, U$1.7
PB7: R7.1, R8.1, U$1.8
PD0: PD0.1, U$1.14
PD1: PD0.2, U$1.15
PD2: PD0.3, U$1.16
PD3: PD0.4, U$1.17
PD4: PD0.5, U$1.18
PD5: PD0.6, U$1.19
PD6: PD0.7, U$1.20
PD7: PD0.8, U$1.21
RS: DIS1.4, U$1.25
RST#: JP1.5, RPU1.1, U$1.9
VADC: CF6.1, LF2.2, U$1.30
VIN: CB1.1, IC1.1, JP3.3
VIN5: CB2.+, CF3.1, CF5.1, IC1.3, JP3.2, LF1.1, LF2.1, U$2.3
VLCD: DIS1.2, R3.1, U$2.1
VUC: CF4.1, JP1.2, LED1.C, LF1.2, RPU1.2, U$1.10

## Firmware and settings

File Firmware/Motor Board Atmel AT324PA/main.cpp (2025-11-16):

/****************************************************************************
**	ROBOTICA@POLITO PROJECT
*****************************************************************************
**	Unit Zero Zero
*****************************************************************************
**	Author: 			Orso Eric
**	Creation Date:
**	Last Edit Date:
**	Revision:			1
**	Version:			0.1 ALPHA
****************************************************************************/

/****************************************************************************
**	HYSTORY VERSION
*****************************************************************************
**	R1 V0.1ALPHA
**		>I wrote a cool function that allow to update servo in one function,
**		i think it's best to update them in sequence to avoid artifact
**		>i rewrote the servo scan function, now it scan the servo in order
**		i eliminated the artifact and greatly reduced var usage and time
**		>added the interpolator function, now servo position is extrapolated
**		from time and points in space and time, offset is accounted for during calculations
**		>global time is now same advancement as servo period
**		~20mS tick, 5.12S longest single movement length
**		>work like a charm
**		>I added the LCD and the trigonometric function library
**		>i moved timer 0 to 156.0uS to update the display and mot is now 156.8*128= 20.07mS
**		>I added progmem capability to the LUT of the trig library to save data memory
**		>tested at_sin8 and at_cos8 by showing them to the display, they seems to work fine
**		>added safe and servo_idle status flags
**		>now the interpolator copy Xe,Te in Xs, Ts when motion end, it setup for next motion and stop the servo
**	V0.2 ALPHA
**		>I vastly improved upon the servo driver. The version I did before
**		is not that user friendly, the user have to meddle with thing to do things.
**		What the user want is to set a position and a speed, and have a flag when 
**		pos is reached. My new driver does just that.
**		The user see three sets of var
**			CONTROL
**			>servo_pos
**			>servo_speed
**			FEEDBACK
**			>servo_lock
**			CONFIG
**			>servo_off
**			>SERVO_MAX_SPEED
**		>Porting to LCD library V3. Here the driver sync the display with a
**		memory. The user can make 1M printchar a second and the driver still
**		won't bug out. Muchbetter abstraction and lower overhead compared
**		to command fifo approach.
**		>Added DPRINTEF macros to at_utils. used in codeblock.
**
**		2025-11-09
**	I'm reporpousing UnitZero firmware 
**	Adding UART and uniparser
**		2025-11-15
**	Added uniparser
**	Redone the project because C++ wasn't working
**	Linked the parser and the serial commands and the callbacks
**	Tested operation from PC terminal and it works!
****************************************************************************/

/****************************************************************************
**	DESCRIPTION
*****************************************************************************
**	This is the control progam for the 5 servos lego 4 leg robots
*****************************************************************************
**	CALCULATION OF TIMER 1 OCR FOR PULSE WIDTH
**	Constant for the conversion from angle (S8) to OCR (U16)
**	x	= [I8] input angle, i use from -127 to +127, -128 is the disable special code
**	Tn 	= [s] (typ 1.5mS) neutral time of the servo, pulse width required for 0°
**	Td	= [s] (typ 0.9mS) maximum skew of the pulse width, from minimum angle (Tn-Td) to maximum angle (Tn+Td)
**	Tt	= [s] (typ 50nS) N/Fclk width of a single stepof the timer, required to calculate the OCR
**	N	= [1] timer prescaler, 1 maximum precision OCR bigger (might require 16bit), 2^n OCR smaller lower precision require less bits
**	K0	= [1] Tn / Tt neutral value of OCR
**	K1	= [1] Td / Tt / 127 angle constant, multiply angle to obtain OCR, 127 is the maximum value of the input
**	OCR	= K0 + K1 * x, calculation of OCR
**	Example
**	Fclk = 20e6, N = 1, Tn = 1.5mS, Td = 0.9mS, x = [-127,+127]
**	K0 = 30e3, K1 = 142 (141.7), >>>OCR = 30e3 + x*142<<<
**	SERVO OFFSET:
**	This is the correction for the 0 position, it is added during the caluclation
**	and does not eat into the servo position range
**	JOINTS:
**	Index		|	Joint		|	Increase position move toward what?
**	-------------------------------------------------------------------
**	0			|	front DX	|	front
**	1			|	front SX	|	back
**	2			|	rear SX		|	back
**	3			|	rear DX		|	front
**	4			|	front hip	|	rise 0, lower 1
**	5			|	rear hip	|	rise 3, lower 2
*****************************************************************************
**	INTERPOLATOR
**	Above the timing ISR for the servo there is the interpolator that generate the positions
**	The user write the wished positions and times in the following global vars
**		Xs	Ts	Xe	Te
**	0
**	...
**	5
**	The time is in tick unit (about 80mS), example:
**	servo_global_time = 45 		//i'm in the 45° tick of the cycle
**	SERVO_POS( 0 , 3 ) = -50	//i start the new motion from current time and in position -50 (50/127*90°=-35.4°)
**	SERVO_TIME( 0 , 3 ) = 45
**	SERVO_POS( 1 , 3 ) = -30	//i end the new motion in 480mS and in position -30 (50/127*90°=-21.3°)
**	SERVO_TIME( 1 , 3 ) = 45+6
**	The interpolator is a powerful function, allow for much easier high level motion generation
**	since it handle all the complexity of sub angle calculation and the timing routine
**	handle all the complexity of the time generations
****************************************************************************/

/****************************************************************************
**	USED PIN
**	TIPS: compile this field before writing any code: it really helps!
*****************************************************************************
**	PB0			|	SERVO 0 - Wheel RX
**	PB1			|	SERVO 1 - Wheel LX
**	PB2			|	
**	PB3			|	
**	PB4			|	
**	PB5			|	
**	PB6			| 	
**	PB7			|	SERVO 7
**	
**	PD0			|	UART0 RXI
**	PD1			|	UART0 TX0
**	PD2			|	L
*****************************************************************************
**
****************************************************************************/

/****************************************************************************
**	USED PHERIPERALS
**	TIPS: compile this field before writing any code: it really helps!
*****************************************************************************
**	HS-311 Servo
**	Voltage		|	5.0
**	Current		|	7m (idle)		160m (free)		700m (stall)
**	Torque		|	3 [Kg*cm]		294 [mNm]
**	Angle		|
**	Control		|	1.5mS (center)	+/-900uS (90°)	~20mS (period)
**				|	HZ -> no force
**				|	positive DT -> clockwise direction
**	UART		| 
*****************************************************************************

**
****************************************************************************/

/****************************************************************************
**	KNOWN BUG
*****************************************************************************
**	>
****************************************************************************/

/****************************************************************************
**	TODO
*****************************************************************************
**
****************************************************************************/

/****************************************************************************
**	ENVROIMENT VARIABILE
****************************************************************************/

/****************************************************************************
**	INCLUDE
**	TIPS: ".h" should not include other ".h", it lower the legibility of the code
**	TIPS: ".h" must not contain anything that generate code, write only declaration or prototype
**	this help the legibility and the debug phase
**	TIPS: type from the stdint.h have a well defined width and signedness, use them
**	( uint8_t = unsigned 8 bit, int8_t = signed 8 bit, uint32_t = unsigned 32 bit, etc... )
****************************************************************************/

#include "global.h"

//Parse commands and calls callback functions automagically
#include "uniparser.h"

//Movement
#include "st_wheel_speed_duration.h"

//Sequence movements with duration
#include "cl_motion_queue.hpp"

/****************************************************************************
**	DEFINE
****************************************************************************/

//define for the mail loop
#define EVER (;;)

/****************************************************************************
**	MACRO
****************************************************************************/

/****************************************************************************
**	STRUCTURE
****************************************************************************/

/****************************************************************************
**	PROTOTYPE: FUNCTION
**	TIPS: use "extern" in function prototype, it's not necessary, but any other
**	prototype need it, it help the legibility of the code
****************************************************************************/

extern U8 seesaw();

extern uint8_t demo_velocity();

extern uint8_t demo_timed_velocity();

extern bool init_parser_commands( Orangebot::Uniparser &i_rcl_parser );



/****************************************************************************
**	PROTOTYPE: GLOBAL VARIABILE
****************************************************************************/

/****************************************************************************
**	GLOBAL VARIABILE:
**	TIPS: "const" variable will be loaded in the flash memory, saving the ram,
**	use it for string that will not be modified
**	TIPS: if you want a ISR to manipulate a global variable, than that variable
**	**must** be declared "volatile" so that the c compiler will not wipe out the
**	variable by optimizing the code, use that variable as less as possible
**	because it will not be optimized
**	TIPS: "volatile int" variable may give problem, don't use it (uP is 8 bits, while
**	int is 16 bits, it's implemented by concatenating 2 byte, the volatile statement
**	disable the optimization on that variable, and mess up that code)
****************************************************************************/

	//-----------------------------------------------------------------------
	//	STATUS VARS
	//-----------------------------------------------------------------------

//Those are the flags updated by ISRs
volatile Isr_flags f;
//Status variable for the servos, keep track of which servo to do next
volatile U8 servo_cnt	= N_SERVOS;

	///----------------------------------------------------------------------
	///	BUFFERS
	///----------------------------------------------------------------------
	//	Buffers structure and data vectors

//Safe circular buffer for UART input data
volatile At_buf8_safe uart_rx_buf;
//Safe circular buffer for uart tx data
At_buf8 uart_tx_buf;
//allocate the working vector for the buffer
U8 v0[ UART_RX_BUF_SIZE ];
//allocate the working vector for the buffer
U8 v1[ UART_TX_BUF_SIZE ];

	//-----------------------------------------------------------------------
	//	UART PARSER
	//-----------------------------------------------------------------------

//Create a new parser
Orangebot::Uniparser g_cl_parser;
	
Cl_motion_queue g_cl_motion_queue;
	
	//-----------------------------------------------------------------------
	//	SERVOS VARS
	//-----------------------------------------------------------------------

//One flag per servo. '1' if the servo is keeping up with target_pos
U8 servo_lock			= 0x00;
//Current position of the servos. Used by the driver, user should not write here
U16 servo_delay[ N_SERVOS ];
//Target position. The user write here, the driver will do it's best to reach it
S8 servo_target_pos[ N_SERVOS ];
//The servo will rotate at this speed [unit/second]
U8 servo_target_speed[ N_SERVOS ];
//servo position offset for true 0 position
//offsets are accounted for in separately from the position, it does not eat into the dynamic
S8 servo_off[ N_SERVOS ];

	//-----------------------------------------------------------------------
	//	TRAJECTORY VARS
	//-----------------------------------------------------------------------

//Timebase for trajectory generation. 1 time unit = 1/50Hz.
U16 servo_global_time 	= 0;
//Current motion plan
//Trajectories trajectory = MOVE_IDLE;



//Operation mode of the servomotors
E_servo_mode g_e_servo_mode = SERVO_SPEED_MODE;

/****************************************************************************
**	MAIN
****************************************************************************/

int main( void )
{
	///**********************************************************************
	///	LOCAL VARIABILE
	///	TIPS: main local variable last the entire program, but unlike the global variable,
	///	they are not visible from other function, the c compiler can better optimize them
	///**********************************************************************

	//temp vars
	U8 u8t;
	U16 u16t;
	//S8 s8t;

	U8 pre_traj = 0;

	///**********************************************************************
	///	VARIABILES INITIALISATION
	///**********************************************************************
	
		///UART RX BUFFER INIT
	//I init the rx and tx buffers
	//attach vector to buffer
	AT_BUF_ATTACH( uart_rx_buf, v0, UART_RX_BUF_SIZE);
	//attach vector to buffer
	AT_BUF_ATTACH( uart_tx_buf, v1, UART_TX_BUF_SIZE);
	
	//Clear global servo time
	//Initialize servo position to zero (offset is accounted for during calculations, i must not add it here)
	for (u8t = 0;u8t < N_SERVOS;u8t++)
	{
		servo_off[u8t]			= +0;
		servo_delay[u8t] 		= K0;	//Servo true position
		servo_target_pos[u8t] 	= +0;	//Servo target position (user)
		servo_target_speed[u8t]	= MOVE_SPEED;	//Servo target speed (default)
	}

	///**********************************************************************
	///	PHERIPERALS INITIALISATION
	///**********************************************************************

	//Initialize devices
	global_init();
	//Register the commands for the parser
	init_parser_commands( g_cl_parser );
	
	//The proud name of this unit
	lcd_print_str( LCD_POS(0,0), (U8 *)"RAMIE");
	lcd_print_str( LCD_POS(0,8), (U8 *)"CMD:");
	lcd_print_str( LCD_POS(1,0), (U8 *)"Time:");

	///**********************************************************************
	///	MAIN LOOP
	///**********************************************************************

	for EVER
	{
		//-----------------------------------------------------------------------
		//	LCD DIPSPLAY UPDATE
		//-----------------------------------------------------------------------
		//	call the lcd display driver

		//If: update the LCD display (10KHz)
		if (f.lcd_update == 1)
		{
			f.lcd_update = 0;
			//Update display
			lcd_update();
		}

		//-----------------------------------------------------------------------
		//	START MOTOR SCAN (5.8uS max all servo functions)
		//-----------------------------------------------------------------------
		//	Flag raised by [Timer 0]
		//	>activity pin (led signal uC use, oscilloscope allow to measure function times)
		//	>clear servo status var
		//	>calculate first delay, pull down first line
		//	>setup first delay, enable [Timer 1]
		//	>Timer 1 ISR will handle the update of the servos and disable it self when done

		//If: Start Servo Scan (50Hz)
		if (f.servo_scan == 1)
		{
			//clear flag
			f.servo_scan = 0;
				//Startup the servo scan
			//clear status var
			servo_cnt 	= 0;
			//calculate delay
			u16t		= servo_calc_delay( 0 );
			//Store delay on T1
			OCR1A 		= u16t;
			//start T1
			START_TIMER1();
			//pull up first line
			SET_BIT( SERVO_PORT, 0 +SERVO_PIN_OFFSET );
				//Advance global time by one tick
			servo_global_time++;
			lcd_print_u16( LCD_POS(1,6), servo_global_time );

			pre_traj = AT_TOP_INC( pre_traj, MOVE_STEP_TIME );
			if (pre_traj == 0)
			{
				f.servo_traj = 1;
			}
			
			//In timed servo mode
			if (g_e_servo_mode == E_servo_mode::SERVO_TIMED_SPEED_MODE)
			{
				St_wheel_speed_duration st_timed_speed;
				//Ask the orchestrator for a motion
				bool x_fail = g_cl_motion_queue.execute_time_step( st_timed_speed );
				//If no motion in the queue
				if (x_fail == true)
				{
					//Stop the motors
					servo_target_pos[SERVO_WHEEL_RIGHT] = 0;
					servo_target_pos[SERVO_WHEEL_LEFT] = 0;
					//Go back to direct speed mode
					//g_e_servo_mode = E_servo_mode::SERVO_SPEED_MODE;
				}
				else
				{
					
					servo_target_pos[SERVO_WHEEL_RIGHT] = st_timed_speed.s8_speed_right;
					servo_target_pos[SERVO_WHEEL_LEFT] = st_timed_speed.s8_speed_left;
				}
				
			}
			
		}	//End If: motor scan flag

		//-----------------------------------------------------------------------
		//	TRAJECTORY GENERATION
		//-----------------------------------------------------------------------

		if (f.servo_traj == 1)
		{
			f.servo_traj = 0;
			
			//lcd_print_u16( LCD_POS(0,11), g_u8_command_counter );
			
			uint8_t u8_queue = g_cl_motion_queue.get_num_element();
			lcd_print_u16( LCD_POS(0,11), u8_queue );
			
			//Signal to user the speed mode
			if (g_e_servo_mode == E_servo_mode::SERVO_SPEED_MODE)
			{
				lcd_print_str( LCD_POS(1,14), (U8 *)"DS" );
			}
			else if (g_e_servo_mode == E_servo_mode::SERVO_TIMED_SPEED_MODE)
			{
				lcd_print_str( LCD_POS(1,14), (U8 *)"TS" );
			}
			
			//Debug send via UART
			//AT_BUF_PUSH( uart_tx_buf, 'A'+g_u8_command_counter );
			//TOGGLE_BIT( PORTD, PD1 );
			
			//Toggle LED
			TOGGLE_BIT( PORTC, PC0 );
			
			//seesaw();
			
			//demo_timed_velocity();
			
		} //END: Trajectory generation
		
		///----------------------------------------------------------------------
		/// UART RX
		///----------------------------------------------------------------------
		//	Handle RX from RS232
		//	Loopback

		//if: uart rx buffer is not empty
		if ( AT_BUF_NUMELEM( uart_rx_buf ) > 0)
		{
			///Get data
			//Get the byte from the RX buffer (ISR put it there)
			u8t = AT_BUF_PEEK( uart_rx_buf );
			AT_BUF_KICK_SAFER( uart_rx_buf );
			///Loopback
			//Push into tx buffer
			//AT_BUF_PUSH( uart_tx_buf, u8t );
			
			//Feed the byte to the parser for decoding
			//It will take care to call the callback functions
			g_cl_parser.parse( u8t );
		}
			
		///----------------------------------------------------------------------
		/// UART TX
		///----------------------------------------------------------------------

		//if: the Uart0 HW buffer is empty and the UART tx buffer is not empty
		if ( (UART0_TX_READY()) && (AT_BUF_NUMELEM( uart_tx_buf ) > 0) )
		{
			//Get the byte to be filtered out
			u8t = AT_BUF_PEEK( uart_tx_buf );
			AT_BUF_KICK( uart_tx_buf );
			//Write on UART tx buffer.
			UDR0 = u8t;

			//lcd_print_char( LCD_POS( 1, 14), u8t );
		}	//End If: uart tx
	}	//end for: for EVER

	return 0;
}	//end main

/****************************************************************************
** FUNCTION:
****************************************************************************/

U8 seesaw()
{
	//static U8 u8_cnt = 0;
	static U8 u8_dir = 0;
	
	servo_target_speed[0] = 5;
	
	if (u8_dir == FALSE)
	{
		servo_target_pos[0] += 1;
		if (servo_target_pos[0]>=10)
		{
			u8_dir = TRUE;
		}
	}
	else
	{
		servo_target_pos[0] -= 1;
		if (servo_target_pos[0]<=-10)
		{
			u8_dir = FALSE;
		}
	}
	
	servo_target_pos[1] = servo_target_pos[0];
	
	return 0;
}


//Feed timed velocity instructions directly into the RX queue to test the decoding
uint8_t demo_velocity()
{
	static uint8_t u8_cnt = 0;
	uint8_t u8_index = 0;
	
	if (u8_cnt == 0)
	{
		
		//const char *ps8_cmd = "VT5R+10L-10\0";
		const char *ps8_cmd = "VR+10L-10\0";
		
		while (ps8_cmd[u8_index] != '\0')
		{
			AT_BUF_PUSH_SAFER( uart_rx_buf, ps8_cmd[u8_index++] );
		}
		AT_BUF_PUSH_SAFER( uart_rx_buf, '\0' );
		u8_cnt++;
	}
	else if (u8_cnt == 1)
	{
		const char *ps8_cmd = "VR-10L+10\0";
		
		while (ps8_cmd[u8_index] != '\0')
		{
			AT_BUF_PUSH_SAFER( uart_rx_buf, ps8_cmd[u8_index++] );
		}
		AT_BUF_PUSH_SAFER( uart_rx_buf, '\0' );
		u8_cnt=0;
	}
	else
	{
		u8_cnt=0;
	}
	
	return 0; //OK
}

/****************************************************************************
**	SERVO CALC POS
*****************************************************************************
**	This function will calculate the delay that move servo[index] closer to the target position
**		SLEW RATE LIMITER: The function will only move at the speed set by the user
**		OFFSET CORRECTION:	In this function i account for mechanical misalignement
**	Formula:
**	xpos = xtarget if ABS(xtarget -xpos) < xspeed/50
**	delay[OCR] = K0 + K1*xoff + K1*xpos
****************************************************************************/
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

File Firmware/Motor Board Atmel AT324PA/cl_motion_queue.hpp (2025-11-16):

/*  CircularMotionQueue.hpp
 *
 *  Micro‑controller friendly FIFO queue that stores wheel speed/duration
 *  structures.
 */

#include <stdint.h>

/*--------------------------------------------------------------
 *  Circular queue class
 *--------------------------------------------------------------*/

class Cl_motion_queue
{
    public:
        /* public constants ---------------------------------------------------*/

        //Queue Size
        static const uint8_t cu8_queue_size = 16;

        /* constructor --------------------------------------------------------*/
        inline Cl_motion_queue()
        {
            this->g_u8_bottom = 0;
            this->g_u8_top = 0;
            this->g_x_run = false;
            return;
        }

        /*--------------------------------------------------------------
         *  Queue manipulation
         *--------------------------------------------------------------*/

        /* push a new element. Returns true if the queue is full (push fails) */
        inline bool push(const St_wheel_speed_duration &i_rst_item)
        {
            uint8_t u8_next = (this->g_u8_top >= this->cu8_queue_size)?(0):(this->g_u8_top + 1u);

            /* queue full */
            if (u8_next == this->g_u8_bottom)
                return true; //FAIL

            this->gst_queue[this->g_u8_top] = i_rst_item;
            this->g_u8_top = u8_next;
            return false; //OK
        }

        /* peek the oldest element without removing it.
         * If the queue is empty, the returned object has zero speeds. */
        inline bool peek( St_wheel_speed_duration &o_rst_item ) const
        {
            if (this->empty() == true)
            {
                o_rst_item.s8_speed_right = 0;
                o_rst_item.s8_speed_left  = 0;
                o_rst_item.u8_duration = 0;
                return true; //FAIL
            }
            o_rst_item = this->gst_queue[this->g_u8_bottom];
            return false; //OK
        }

        /* pop the oldest element. Returns true if an element was removed,
         * otherwise false (queue empty). */
        inline bool pop(void)
        {
            if (this->empty())
                return true; //FAIL

            this->g_u8_bottom = (this->g_u8_bottom + 1u) % this->cu8_queue_size;
            return false; //OK
        }

        /* flush queue – reset to empty state. */
        inline bool flush(void)
        {
            this->g_u8_bottom = 0;
            this->g_u8_top    = 0;
            return false; //OK
        }

		//Return the number of motions queued
		inline uint8_t get_num_element()
		{
			return ( (this->g_u8_top >= this->g_u8_bottom) ? (this->g_u8_top-this->g_u8_bottom) : (this->cu8_queue_size-this->g_u8_bottom+this->g_u8_top) );
		}

        /*--------------------------------------------------------------
         *  Execution helpers
         *--------------------------------------------------------------*/

        inline bool set_run( bool i_x_run )
        {
            this->g_x_run = i_x_run;
            return false; //OK
        }

        /* execute one time‑step.
         *
         * i_rst_out will be filled with the current wheel speeds and
         * duration remaining. If the queue is empty or paused,
         * zero speeds are returned and the function returns true.
         *
         * When a command finishes (duration reaches 0) it is removed
         * automatically for the next call.
         */
        inline bool execute_time_step(St_wheel_speed_duration &i_rst_out)
        {
            if ( (this->g_x_run==false) || (this->empty()==true) )
            {
                i_rst_out.s8_speed_right = 0;
                i_rst_out.s8_speed_left  = 0;
                i_rst_out.u8_duration = 0;
                return true;          /* queue empty or paused */
            }

            /* active element is at the head of the queue */
            St_wheel_speed_duration &rst_item = this->gst_queue[this->g_u8_bottom];

            /* copy current state to output */
            i_rst_out.s8_speed_right = rst_item.s8_speed_right;
            i_rst_out.s8_speed_left  = rst_item.s8_speed_left;
            i_rst_out.u8_duration = rst_item.u8_duration;

            /* decrement duration of the active element */
            if (rst_item.u8_duration > 0u)
            {
                rst_item.u8_duration--;
            }

            /* if finished, pop it */
            if (rst_item.u8_duration == 0u)
            {
                this->pop();
            }

            return false; //OK
        }

        inline bool empty(void) const
        {
            return this->g_u8_bottom == this->g_u8_top;
        }

    private:
        /* queue storage ---------------------------------------------*/
        St_wheel_speed_duration gst_queue[cu8_queue_size];

        /* indices: g_u8_bottom → oldest element
         *           g_u8_top    → next free slot                */
        uint8_t g_u8_bottom;
        uint8_t g_u8_top;

        /* run flag ---------------------------------------------------*/
        bool g_x_run;   /* true = executing, false = paused */


};

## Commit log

2025-11-15 Added link for track Added folder structure
2025-11-15 This is a board that I designed in 2012 to control robots It was convenient for me to use this board as I have a bounch of them assembled It has an Atmel AT324PA, an ISP programmer, power and breaks 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
    [AT324LCD_V1.GBL, AT324LCD_V1.GBS, AT324LCD_V1.GKO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]
2025-11-15 Added images and documentation for the motor control board
2025-11-15 Linked documentation for the motor control board Updated main readme with link to the motor control board readme
    https://github.com/B-AROL-O/RAMIE-RAD_AI_Messing_In_Earthworks/issues/1
    https://github.com/B-AROL-O/RAMIE-RAD_AI_Messing_In_Earthworks/issues/3
2025-11-15 Adapted from Unit Zero (2019) and Industrious Resonance (2025)
    Firmware to control the motor Board
    PPM signal for continuous rotation servo motors
    LCD screen with parallel protocol
    UART link to communicate with SBC
    TODO: Develop a communication protocol that works with MCP server GRADIO
    https://github.com/B-AROL-O/RAMIE-RAD_AI_Messing_In_Earthworks/issues/5
    [global.h, main.c]
2025-11-15 Test bench for the serial communicaton and callback function on Firmware https://github.com/B-AROL-O/RAMIE-RAD_AI_Messing_In_Earthworks/issues/5
    [example.cpp, parser_handlers.cpp, serial_parser.cpp]
2025-11-15 Added the codeblock test bench for motion orchestration class. https://github.com/B-AROL-O/RAMIE-RAD_AI_Messing_In_Earthworks/issues/5
    [cl_motion_queue.hpp, main.cpp]
2025-11-15 OpenSCAD Holder for 18650 batteries developed over several years
    Configurations
    - 1S1P
    - 2S1P
    - 2S2P
    - 2S2P upside down
    https://github.com/B-AROL-O/RAMIE-RAD_AI_Messing_In_Earthworks/issues/10
    [2024-06-02 MP2 Belly Plate V0.stl, 2024-06-13_18_21_18650_single_prototype.stl, 2024-06-20_18_17-2s2p-prototype.stl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]
2025-11-15 Fixed readme for the battery holder https://github.com/B-AROL-O/RAMIE-RAD_AI_Messing_In_Earthworks/issues/10 https://github.com/B-AROL-O/RAMIE-RAD_AI_Messing_In_Earthworks/issues/1
2025-11-15 OpenSCAD design of the platform This is recycled from Industrious Resonance that is already a Latte Panda Mu platform under development I do need to refine it as it was not finished https://github.co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
    [battery-18650-holder.scad, battery-18650-tabs.scad, battery-18650.scad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]
2025-11-15 Added images of the design process of the wheeled platform. This was lots of work I did for Industrious Resonance but it worked out great I have a pivot ping pong ball, HS422 servo holders, all tolle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
    TODO: geometry for the electronics and details. I decided to print an intermediate step.
2025-11-15 BUG: if I have a command with argument VR%L% and a command VR%L%T% the parser gets confused and cannot match.
    [parser_handlers.cpp, serial_parser.cpp]
2025-11-15 Changed name on LCD to RAMIE Powered Uploaded Connected UART Loopback works
    Now I just need to link the parser
    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
    [global.h, main.c, parser_handlers.cpp]
2025-11-15 doesn't compile. something with C++? -.-
    [initialisation.cpp, main.cpp]
2025-11-15 FRACK YEAH it works! I had just some issue with initialization. Done a video and tested ping and speed commands and they work. The F signature command doesn't, it's likely an infinite loop. I didn't 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
    [main.cpp]
2025-11-16 Fixed SIGN and REV messages. Added aid function to send strings. https://github.com/B-AROL-O/RAMIE-RAD_AI_Messing_In_Earthworks/issues/5
    Documentation for the communication protocol.
    https://github.com/B-AROL-O/RAMIE-RAD_AI_Messing_In_Earthworks/issues/6
    [global.h, main.cpp, parser_handlers.cpp]
2025-11-16 Install UV VENV Remember this is windows not linux pyserial library should work on both? Baud rate is 250Kb/s
    DEMO 1 is about enumerating ports
    DEMO 2 is about sending a signature command and getting an answer
    https://github.com/B-AROL-O/RAMIE-RAD_AI_Messing_In_Earthworks/issues/15
    [demo_2_ask_signature.py]
2025-11-16 DEMO 3 The code sends every 250ms increase speed on R by increment of 10 up to 50 Then decrement in speed -10 down to -50 then increment of +10 up to 0 then do the same on L speed repeat
    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
    [demo_3_serial_direct_speed.py]
2025-11-16 Linked Python demo to the board section main README https://github.com/B-AROL-O/RAMIE-RAD_AI_Messing_In_Earthworks/issues/1 https://github.com/B-AROL-O/RAMIE-RAD_AI_Messing_In_Earthworks/issues/15
2025-11-16 Added a demo inside the firmware that loads commands into the UART RX buffer directly
    This way I can test the parser without using the terminal.
    https://github.com/B-AROL-O/RAMIE-RAD_AI_Messing_In_Earthworks/issues/18
    [cl_motion_queue.hpp, main.cpp]
2025-11-16 implemented //Enumerates modes of operation of the servo motors enum E_servo_mode { //Direct speed mode will sustain the speed given until different instruction SERVO_SPEED_MODE, //Timed servo mode w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
    when sending a direct speed command goes into DS and sustain last speed
    when sending a timed speed, goes into TS mode and use the orchestrator, if the queue is empty, it stops moving
    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
    [global.h, main.cpp, parser_handlers.cpp]
2025-11-16 Firmware for motion orchestration done, filmed video Showed switch between DS and TS Showed loading of the queue and timed execution
    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
    [main.cpp]
2025-11-17 Used kicad to convert and measure the AT324 board In Openscad modelling the sloped support wall Done the trigonometry to decide on the board angle
    [AT324LCD_V1.kicad_pcb, board_at324_support.scad]
2025-11-17 Building the mechanical support for AT324 I did a lot of fancy trigonometry to find where to drill
    [AT324 Slope.ods, board_at324_support.scad]
2025-11-17 Did precision drills for the screw! TODO: Now I just need to tip them with an hole for the nut
    [board_at324_support.scad]
2025-11-18 Added screenshot of design progress
    [AT324 Slope.ods]
2025-11-18 completed wall with slope and drill with all fancy trigonometry nailed down. made it into a shape library created the box model for the AT324 LCD board
    [AT324 Slope.ods, board_at324.scad, board_at324_support.scad]
2025-11-18 committing geometry done on bus.
    [board_at324_support.scad]
2025-11-18 constructed sloped support walls for the AT324 module updated README TODO: add drills for a bolt for power
    [board_at324.scad, board_at324_support.scad, hull_lpmu.scad]
2025-11-18 I added an hole on the support for power bolts i generated stl so i can print the shape_wall_sloped_with_bolt_nut and hot glue them to the robot for fun and profit
    [shape_wall_sloped_with_bolt_nut.stl]
2025-11-19 Printed support for AT324 with hotglue Failed print but okay for prototype Added photos for other sections https://github.com/B-AROL-O/RAMIE-RAD_AI_Messing_In_Earthworks/issues/21
2025-11-20 tested possible system prompt for trajectories on Gemma 3 4B Q4 Vision Instruct. it's mhe it does generate mostly valid strings but it cannot count right and it does exceed the argument parameters at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
2025-11-21 FRACK!!! So I added LM Studio inference to Alessio code expecting it to tool call it doesn't, the fracker just prints outuseless code to do manually a tool call. it turns out Gemma 3 4B Q4 Vision Ins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
    Gemma (and most llama.cpp based models) can’t interpret the functions/tool_calls protocol that OpenAI’s GPT‑4 or Anthropic’s Claude use.
    They only generate code or textual hints, which is why you see the tool_code block.
    Your client didn’t act on a too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
2025-11-22 I was trying to resurrect the N100 16GB Server Passive to no avail
    I worked on the N100 8GB Desktop Active
    I need to modify grub to activate the serial
    Speed 9600 and 115200 work
    Speed 250000 doesn't and default to 9600
    Putty serial connection work. Terminal serial view dump works
    I cannot resurrect the bricked board since I need to modify grub and i'm locked out hard.
    https://github.com/B-AROL-O/RAMIE-RAD_AI_Messing_In_Earthworks/issues/29
2025-11-22 Configure the GRUB to use ttyS0 as UART serial interface to let the host connect via putty via USB to UART FTDI adapter
    Added documentation and instructions
    Added link to main readme
    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
2025-11-23 Reorganized software and main readme
    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
    [demo_2_ask_signature.py, demo_3_serial_direct_speed.py]
2025-11-23 This was not straightforward I had to go deep with oscilloscope to find out why the python link from SBC to AT324 wasn't working while it was working fine under windows It turns out linux has discret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
    I moved application to 115200 b/s
    I moved the firmware to 113636 b/s
    Now it communicates fine.
    I'll need to significantly accelerate the communication for the future
    I need to find discrete steps that work both on linux, and on firmware
    because on firmware I have a lower clock that gives me wider steps due to prescaler settings
    I feel 500Kb/s works on both
    https://gi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
    [global.h]
2025-11-23 DEMO from 1 to 4 run fine directly on SBC communicating with AT324 and moving motors
    https://github.com/B-AROL-O/RAMIE-RAD_AI_Messing_In_Earthworks/issues/32
    [demo_2_ask_signature.py, demo_3_ask_signature_single_port_loop.py, demo_4_serial_direct_speed.py]
2025-11-23 Reordered files, updated readme
    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
    [demo_2_ask_signature.py, demo_3_ask_signature_single_port_loop.py, demo_3_serial_direct_speed.py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]
2025-11-23 This was easy, console application to move robot when keys are pressed.
    Next the big one, do it all from battery power.
    https://github.com/B-AROL-O/RAMIE-RAD_AI_Messing_In_Earthworks/issues/22
    [demo_teleoperation.py]
2025-11-23 Added on eln and main readme the video
    https://github.com/B-AROL-O/RAMIE-RAD_AI_Messing_In_Earthworks/issues/34
    Issue with powering SBC. WHY?=???
    https://github.com/B-AROL-O/RAMIE-RAD_AI_Messing_In_Earthworks/issues/35
2025-11-30 Track mp4 files with Git LFS
